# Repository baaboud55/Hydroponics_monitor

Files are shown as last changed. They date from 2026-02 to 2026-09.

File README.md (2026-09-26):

<div align="center">

# 🌿 HydroMisc — Autonomous Hydroponics Monitor

**An open-source, full-stack precision hydroponics controller.**  
Custom PCB · ESP32 Firmware · Python Backend · React Dashboard







</div>

---

## 📖 Overview

**HydroMisc** is a complete, production-ready hydroponics monitoring and autonomous dosing system. It was designed from the ground up to be a consumer appliance — you plug it in, connect to WiFi, select your crop, and the system automatically maintains optimal growing conditions 24/7.

The system is built around a **custom ESP32-based PCB** that reads sensors, drives actuators, and hosts the web interface directly from its flash filesystem — all without needing an internet connection.

### ✨ Key Features

| Feature | Description |
|---|---|
| 🔬 **Multi-Sensor Monitoring** | pH, EC, Dissolved O₂, Water Temp, Air Temp, Humidity, VPD, Water Level, Power Current |
| 🤖 **Autonomous PID Dosing** | Auto-maintains pH and EC using configurable PID controllers with safety limits |
| 🌐 **Zero-Touch Consumer UX** | Select a crop → system sets targets automatically. Accessible from any device on your network |
| 📡 **Real-time WebSocket Dashboard** | Live sensor data streamed to all connected browsers simultaneously |
| 📱 **Cross-Device Sync** | Backend is the single source of truth — phone and PC stay perfectly in sync |
| 💧 **8-Solenoid Irrigation Control** | Full control over 8 solenoid valves via shift register |
| ⚡ **OTA Firmware Updates** | Update firmware wirelessly via Arduino OTA or HTTP update server |
| 🗓️ **Dosing History Log** | All auto-dosing events persisted to SQLite for audit and analysis |

---

## 🏗️ System Architecture

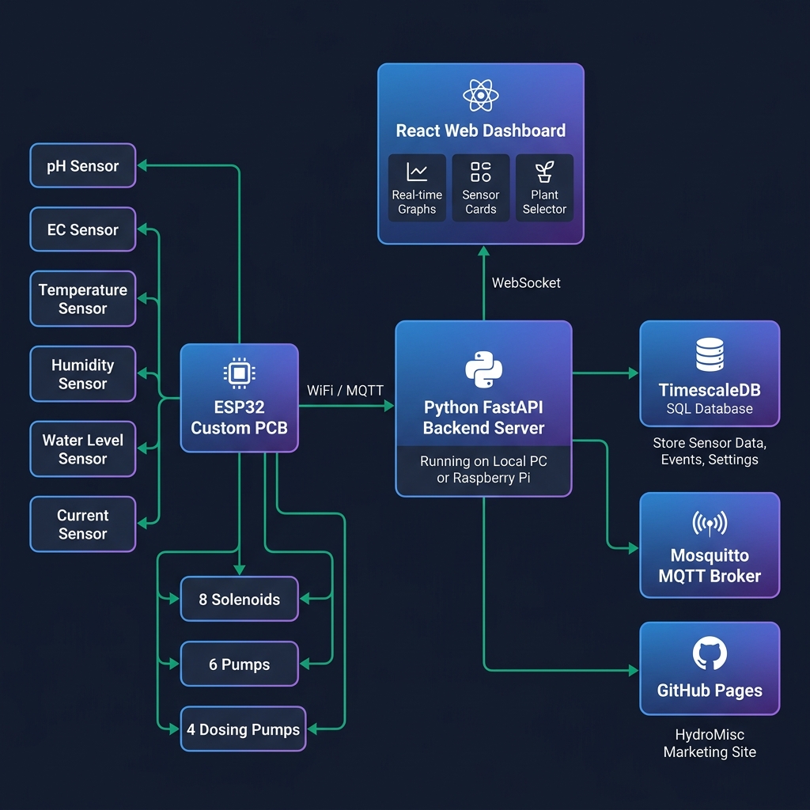
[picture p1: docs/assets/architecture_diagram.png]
System Architecture


### Data Flow

```
ESP32 Custom PCB
  ├── Reads sensors every loop cycle
  ├── Runs autonomous PID control (HydroControl library)
  ├── Serves the React dashboard via LittleFS (port 80)
  └── Publishes sensor data via MQTT
           │
           ▼  WiFi / LAN (MQTT port 1883)
  Python FastAPI Backend
  ├── Subscribes to MQTT sensor topics
  ├── Runs a parallel PID control layer
  ├── Stores config.json and dosing history (SQLite)
  ├── REST API  → http://<host>:8000
  └── WebSocket → ws://<host>:8000/ws
           │
           ▼  WebSocket (real-time push)
  React Web Dashboard
  ├── Consumer View: Plant Selector → System Visualizer
  └── Admin View: Dashboard, Automation, Parameter Config
```

---

## 🗂️ Repository Structure

```
HydroMonitor/
├── firmware/                    # ESP32 PlatformIO project (C++)
│   ├── src/
│   │   └── main.cpp             # Main firmware entry point
│   ├── lib/
│   │   ├── HydroActuators/      # Shift-register solenoid/pump driver
│   │   ├── HydroSensors/        # pH, EC, Temp, Humidity sensor drivers
│   │   ├── HydroDosingPumps/    # Peristaltic dosing pump driver
│   │   ├── HydroControl/        # On-device PID control engine
│   │   └── HydroMQTT/           # MQTT client abstraction
│   ├── data/                    # Web dashboard files (served via LittleFS)
│   └── platformio.ini           # Board config & dependencies
│
├── software/
│   ├── backend/                 # Python FastAPI server
│   │   ├── main.py              # App entry point, API routes, WebSocket
│   │   ├── control_engine.py    # PID controller & safety manager
│   │   ├── config_manager.py    # Persistent configuration (config.json)
│   │   ├── database.py          # SQLite dosing history
│   │   ├── mock_device.py       # MQTT sensor simulator for testing
│   │   └── requirements.txt
│   └── frontend/                # React + Vite dashboard
│       ├── src/
│       │   ├── components/      # UI components (10 total)
│       │   ├── hooks/           # useWebSocket
│       │   ├── services/        # api.js (all REST calls)
│       │   ├── contexts/        # LanguageContext (EN/AR bilingual)
│       │   └── App.jsx          # Router & top-level state
│       └── package.json
│
├── docs/                        # Documentation & GitHub Pages
│   ├── app/                     # GitHub Pages build output
│   └── assets/                  # Diagrams and images
│
└── README.md
```

---

## ⚡ Getting Started

### Prerequisites

| Requirement | Version | Purpose |
|---|---|---|
| Python | 3.10+ | Backend server |
| Node.js | 18+ | Frontend build toolchain |
| PlatformIO | Latest | ESP32 firmware compilation |
| Mosquitto / any MQTT broker | Any | Local MQTT relay (optional) |

---

### 1. Backend Server

```bash
cd software/backend
pip install -r requirements.txt

# Start the server (accessible on your whole local network)
uvicorn main:app --host 0.0.0.0 --port 8000 --reload
```

> On first run, `config.json` is automatically created with safe defaults.

**Key API Endpoints:**

| Method | Endpoint | Description |
|---|---|---|
| `GET` | `/api/state` | Full sensor + automation state snapshot |
| `WS` | `/ws` | Real-time WebSocket stream (1 Hz) |
| `GET` | `/api/config` | Read full configuration |
| `POST` | `/api/config/parameter` | Update pH/EC target or tolerance |
| `POST` | `/api/config/crop/{id}` | Set active crop (syncs to all browsers) |
| `POST` | `/api/config/automation/{param}/{enabled}` | Enable/disable PID automation |
| `GET` | `/api/dosing/history` | Retrieve dosing log |
| `POST` | `/api/dosing/manual` | Trigger a manual pump dose |
| `POST` | `/api/dosing/reset` | Reset PID controller state |
| `POST` | `/api/calibrate` | Send calibration command to ESP32 |
| `POST` | `/api/actuators/solenoid/{index}/{state}` | Control solenoid valve 0–7 |
| `POST` | `/api/actuators/pump/{index}/{state}` | Control circulation pump 0–5 |
| `POST` | `/api/actuators/main_pump/{state}` | Control main circulation pump |

**For testing without hardware**, set `MQTT_ENABLED = False` in `main.py` — the backend will simulate sensor data internally. Alternatively, run the MQTT mock device in a separate terminal:
```bash
python mock_device.py
```

---

### 2. Frontend Dashboard

```bash
cd software/frontend
npm install
npm run dev
```

Dashboard available at **`http://localhost:5173`**.

The app auto-detects the environment:
- **On localhost / local IP** → Boots directly into the Consumer Dashboard (no setup needed)
- **On GitHub Pages** → Boots into the Marketing Demo

To build the production bundle (outputs to `docs/app/` for GitHub Pages and `firmware/data/` for the ESP32 filesystem):
```bash
npm run build
```

---

### 3. Firmware (ESP32)

#### First-time Setup

1. Install [PlatformIO](https://platformio.org/) (VS Code extension recommended).
2. Open the `firmware/` folder in VS Code.
3. Build and upload firmware:
   ```bash
   pio run --target upload
   ```
4. Upload the web dashboard filesystem:
   ```bash
   pio run --target uploadfs
   ```

#### WiFi Configuration

On first boot, the ESP32 creates a WiFi access point:
- **SSID:** `HydroMisc-Setup`
- **Password:** `password`

Connect to it and you'll be automatically redirected to the WiFi configuration portal. Enter your network credentials and the device will restart and connect.

#### OTA (Over-The-Air) Updates

After first setup, you **never need a USB cable again**.

**Via Arduino OTA (PlatformIO):**
```bash
# platformio.ini already has: upload_protocol = espota
pio run --target upload
```

**Via HTTP Update Server:**  
Navigate to `http://hydromonitor.local/update` in your browser and upload a `.bin` file.

#### mDNS / Local DNS

The device registers itself on your network as `hydromonitor.local`. Access the dashboard at:
```
http://hydromonitor.local
```

---

## 📌 GPIO Pinout

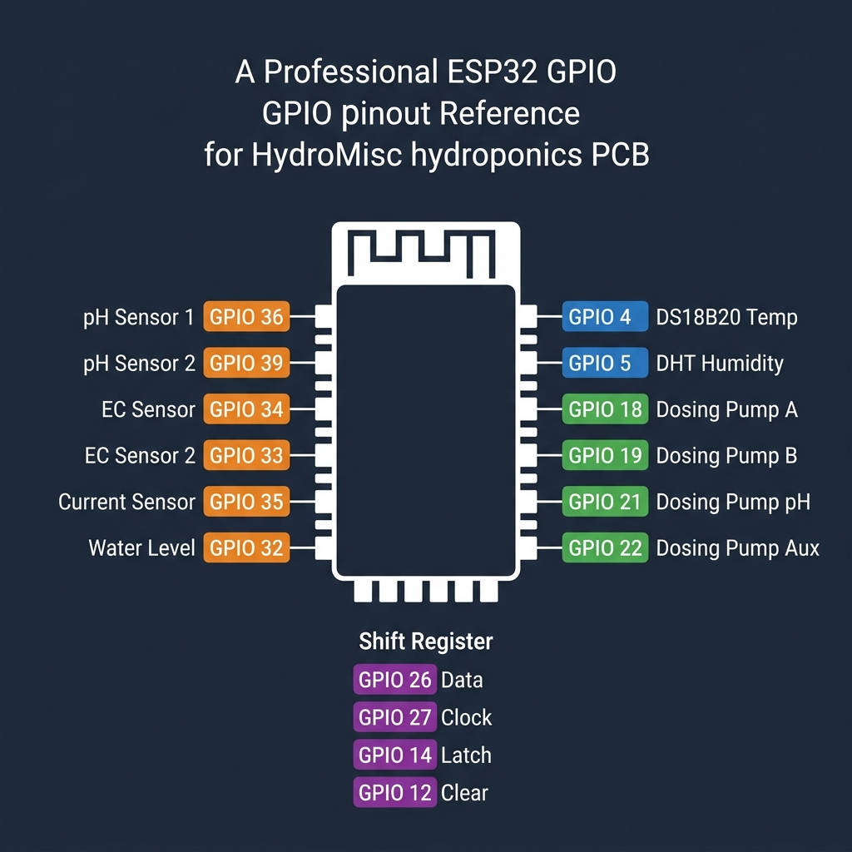
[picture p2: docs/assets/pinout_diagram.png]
Pinout Diagram


### Analog Inputs (Sensors)

| GPIO | ADC Channel | Function |
|---|---|---|
| `36` | ADC1_CH0 | pH Probe (Primary) |
| `39` | ADC1_CH3 | pH Probe (Secondary / Reference) |
| `34` | ADC1_CH6 | EC Probe (EC_0) |
| `33` | ADC1_CH5 | EC Probe (EC_1) |
| `35` | ADC1_CH7 | Current Sensor |
| `32` | ADC1_CH4 | Water Level Sensor / DC Resistance |

### Digital Inputs (Sensors)

| GPIO | Function |
|---|---|
| `4`  | DS18B20 Water Temperature (1-Wire) |
| `5`  | DHT / AM2301 Air Temp & Humidity |

### Actuators — Direct PWM (Dosing Pumps)

| GPIO | Function |
|---|---|
| `18` | Dosing Pump A (Nutrient A) |
| `19` | Dosing Pump B (Nutrient B) |
| `21` | Dosing Pump pH (pH Up/Down) |
| `22` | Dosing Pump Aux (Spare) |

### Actuators — Shift Register (74HC595, 16-bit chain)

| GPIO | Shift Register Pin | Function |
|---|---|---|
| `26` | SI (Data) | Shift Register Data |
| `27` | SCK (Clock) | Shift Register Clock |
| `14` | RCK (Latch) | Shift Register Latch |
| `12` | nRCLR (Clear) | Shift Register Clear (Active Low) |

**Shift Register Bit Map (16 bits):**

| Bits | Assignment |
|---|---|
| 0–7  | Solenoid Valves 0–7 |
| 8–13 | Circulation Pumps 0–5 |
| 14 | Main Pump |
| 15 | Debug Status LED |

### EC Measurement Gates

| GPIO | Function |
|---|---|
| `25` | EC Measurement Gate (+) |
| `15` | EC Measurement Gate (−) |

---

## 🔌 Hardware Wiring Guide (Hydromisc PCBA)

The Hydromisc custom PCBA provides dedicated plug-and-play ports for all hydroponic peripherals.

### PCB Layout Overview
Hydromisc PCBA Top View

### Power Side (Actuators & Pumps)
Power Side Pinout

This side handles all high-current 12V outputs. Note the varying current limits for each block:

```mermaid
flowchart LR
    subgraph Hydromisc Power Ports
        S[Solenoid Ports<br>8x 12V 1.0A]
        P[Pump Ports<br>6x 12V 0.5A]
        D[Dosing Ports<br>4x 12V 0.25A]
    end
    
    WaterValve[12V Solenoid Valve] -.-> S
    MainPump[Small Circulation Pump<br>>250mA] -.-> P
    AirPump[12V Air Pump] -.-> P
    DoseA[Nutrient A Doser<br><250mA] -.-> D
    DoseB[Nutrient B Doser<br><250mA] -.-> D
    DosePH[pH Down Doser<br><250mA] -.-> D
```

### 🔌 Exact Software-to-Hardware Mapping

When you click a button in the HydroMisc Web Dashboard, the software activates a specific port on the board. Follow this diagram to wire your hardware correctly so it works instantly!

```mermaid
flowchart LR
    %% Software Interface Layer
    subgraph Dashboard[🖥️ HydroMisc Web Dashboard]
        BtnMain[Main Pump Toggle]
        BtnCirc[Circulation Pumps 1-5]
        BtnSol[Solenoid Valves 0-7]
        BtnDoseA[Nutrient A Auto-Dose]
        BtnDoseB[Nutrient B Auto-Dose]
        BtnDosePH[pH Down Auto-Dose]
        BtnDoseAux[Aux Auto-Dose]
    end

    %% Hardware Board Layer
    subgraph PCBA[🔌 Hydromisc PCBA Physical Ports]
        PortP0[Pump Port #0<br/>labeled 'big_pump']
        PortP15[Pump Ports #1-5]
        PortS07[Solenoid Ports #0-7]
        PortDA[Dosing Port A]
        PortDB[Dosing Port B]
        PortDPH[Dosing Port pH]
        PortDAux[Dosing Port AUX]
    end

    %% Actuator Layer
    subgraph Actuators[⚙️ Plug Your Hardware Here]
        MainPump[Main Water Cycle Pump<br/>0.5A max]
        CircPump[Air / Circ Pumps<br/>0.5A max]
        Solenoid[Water Valves / Relays<br/>1.0A max]
        PeriA[Peristaltic Pump A<br/>0.25A max]
        PeriB[Peristaltic Pump B<br/>0.25A max]
        PeriPH[Peristaltic Pump pH<br/>0.25A max]
        PeriAux[Peristaltic Pump Aux<br/>0.25A max]
    end

    %% Connections
    BtnMain == Triggers ==> PortP0
    PortP0 -.-> MainPump
    
    BtnCirc == Triggers ==> PortP15
    PortP15 -.-> CircPump
    
    BtnSol == Triggers ==> PortS07
    PortS07 -.-> Solenoid
    
    BtnDoseA == Triggers ==> PortDA
    PortDA -.-> PeriA
    
    BtnDoseB == Triggers ==> PortDB
    PortDB -.-> PeriB
    
    BtnDosePH == Triggers ==> PortDPH
    PortDPH -.-> PeriPH
    
    BtnDoseAux == Triggers ==> PortDAux
    PortDAux -.-> PeriAux

    %% Styling
    classDef soft fill:#1e293b,stroke:#3b82f6,stroke-width:2px,color:#fff;
    classDef hard fill:#14532d,stroke:#22c55e,stroke-width:2px,color:#fff;
    classDef act fill:#450a0a,stroke:#ef4444,stroke-width:2px,color:#fff;
    
    class BtnMain,BtnCirc,BtnSol,BtnDoseA,BtnDoseB,BtnDosePH,BtnDoseAux soft;
    class PortP0,PortP15,PortS07,PortDA,PortDB,PortDPH,PortDAux hard;
    class MainPump,CircPump,Solenoid,PeriA,PeriB,PeriPH,PeriAux act;
```

> 🚨 **CRITICAL WIRING RULE:** Notice in the board images that every single port block has its own dedicated `+12V` and `GND` screw terminal. **DO NOT twist your motor grounds together!** You must strip the two wires for each pump and screw them directly into their own dedicated block. Bridging grounds together forces all power through a single trace and will permanently burn out the PCB!
Sensor Side Pinout

```mermaid
flowchart LR
    subgraph Hydromisc Sensor Ports
        BNC_PH[pH BNC Port]
        BNC_EC[EC BNC Port]
        DIG_0[Digital Expansion 0]
        DIG_1[Digital Expansion 1]
    end
    
    PH_Probe[Commercial pH Probe] -.-> BNC_PH
    EC_Probe[Commercial EC Probe] -.-> BNC_EC
    WaterTemp[DS18B20 Water Temp] -.-> DIG_0
    AirTemp[DHT22 Air Temp/Humidity] -.-> DIG_1
```

---

## ⚙️ Configuration Reference

All parameters are configurable via the dashboard **Config tab** or by editing `software/backend/config.json` directly.

```json
{
  "active_crop": "lettuce",
  "ph": {
    "target": 6.0,
    "tolerance": 0.2,
    "enabled": true,
    "min_value": 4.0,
    "max_value": 8.0
  },
  "ec": {
    "target": 1.5,
    "tolerance": 0.1,
    "enabled": false,
    "min_value": 0.5,
    "max_value": 3.0
  },
  "pid_tuning": {
    "ph": { "kp": 0.5, "ki": 0.1, "kd": 0.05 },
    "ec": { "kp": 0.3, "ki": 0.05, "kd": 0.02 }
  },
  "safety": {
    "max_ph_dose_ml": 50.0,
    "max_ec_dose_ml": 100.0,
    "min_dose_interval_sec": 300,
    "sensor_timeout_sec": 30
  },
  "mqtt": {
    "broker": "192.168.1.100",
    "port": 1883,
    "device_id": "hydro-misc-01"
  }
}
```

### Supported Crop Profiles

When a crop is selected in the dashboard, pH and EC targets are automatically pushed to the backend PID controllers.

| Crop | Target pH | Target EC (mS/cm) | Target Temp |
|---|---|---|---|
| 🥬 Lettuce | 6.0 | 1.0 | 20 °C |
| 🍅 Tomatoes | 6.0 | 2.7 | 23.5 °C |
| 🌿 Basil | 6.0 | 1.3 | 24 °C |
| 🍓 Strawberries | 5.8 | 1.2 | 20.5 °C |

---

## 🚦 LED Status Codes

The debug LED on the PCB communicates system status without needing Serial Monitor access.

| Pattern | Mode | Meaning |
|---|---|---|
| Rapid blink (100ms) | `BOOTING` | System initializing |
| Slow pulse (800ms on/off) | `WIFI_SETUP` | WiFi AP portal is active — connect to configure |
| Fast strobe (50ms) | `OTA_UPDATE` | Firmware upload in progress |
| Heartbeat (double-tap + 1.7s off) | `NORMAL` | Healthy operation |
| Triple flash SOS | `ERROR` | Critical fault — check Serial Monitor |

---

## 📦 Enclosure

The system is designed to be housed in a **panel-mount waterproof enclosure** suitable for a grow room or utility area.

### Recommended Enclosure Specs

- **Type:** IP65-rated ABS plastic enclosure
- **Size:** ~200×120×75mm (adjust for your PCB dimensions)
- **Mounting:** DIN rail clip or M4 wall screws
- Cable gland fittings for all probe cables and pump tubing
- PCB mounted on brass standoffs inside the enclosure
- Position the ESP32 antenna toward the enclosure wall or use an external antenna for best WiFi signal

### External Connections

| Connector Type | Signals |
|---|---|
| BNC or SMA | pH probe(s), EC probe(s) |
| RJ11 / JST-XH | DS18B20 water temperature probe |
| JST-XH 3-pin | DHT / AM2301 air temp & humidity sensor |
| Screw terminal strip | 12V solenoid valve outputs (×8) |
| Screw terminal strip | Dosing pump power lines (×4) |
| Screw terminal strip | Circulation pump relay outputs (×6) |
| Barrel Jack (5.5/2.1mm) | 12V DC power input |
| Micro-USB / USB-C | Programming & Serial monitor |

---

## 🌐 Network & Ports Summary

| Service | Protocol | Port | Notes |
|---|---|---|---|
| ESP32 Web Server | HTTP | **`80`** | Dashboard (LittleFS) + `/api/state` + `/api/config` + `/update` |
| Python Backend API | HTTP | **`8000`** | Full REST API for the dashboard |
| Python WebSocket | WS | **`8000/ws`** | Real-time 1 Hz sensor stream to browser |
| MQTT Broker | TCP | **`1883`** | Sensor data & actuator commands |
| mDNS Discovery | UDP | `5353` | `hydromonitor.local` hostname resolution |
| Serial Monitor | UART | `115200 baud` | Firmware debugging via USB |

---

## 🔄 MQTT Topics

The ESP32 and Python backend communicate over MQTT with the following topic structure:

**Sensor Data (Published by ESP32):**
```
hydro/status/<device_id>/ph
hydro/status/<device_id>/ec
hydro/status/<device_id>/water_temp
hydro/status/<device_id>/air_temp
hydro/status/<device_id>/humidity
hydro/status/<device_id>/water_level
hydro/status/<device_id>/power_current
```

**Actuator Commands (Published by Python Backend → Received by ESP32):**
```
hydro/<device_id>/control/dosing/<pump_index>/dose    → duration in ms
hydro/<device_id>/control/solenoid/<index>            → "1" or "0"
hydro/<device_id>/control/pump/<index>                → "1" or "0"
hydro/<device_id>/control/main_pump                   → "1" or "0"
hydro/<device_id>/control/calibrate/<sensor>          → calibration string
```

> Default `device_id`: `hydro-misc-01` (configurable in `config.json`)

---

## 🖥️ Dashboard

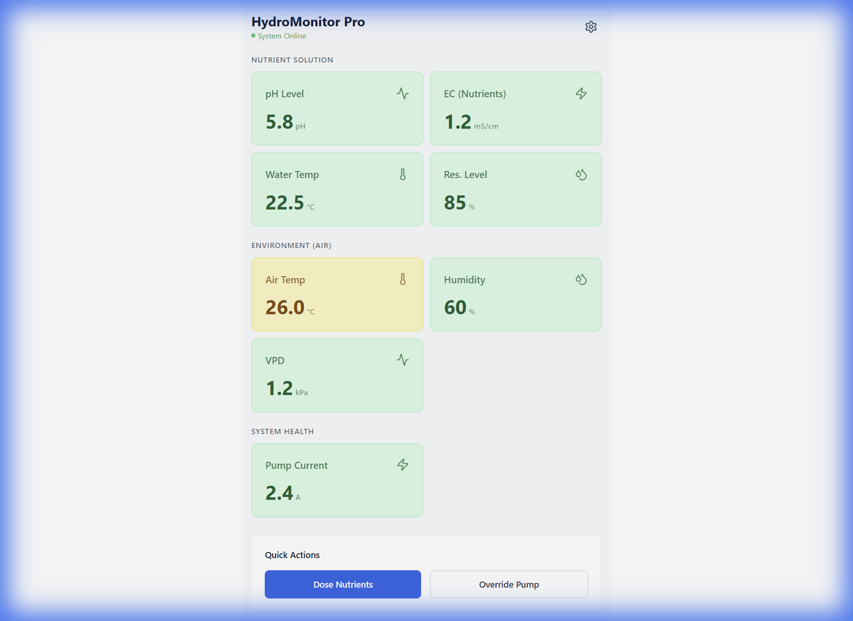
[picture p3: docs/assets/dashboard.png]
Dashboard Screenshot


> **Live Demo:** [https://baaboud55.github.io/Hydroponics_monitor/app/](https://baaboud55.github.io/Hydroponics_monitor/app/)  
> *(Demo mode uses simulated data — no hardware required to explore the full UI.)*

---

## 🏢 About

**HydroMisc** is developed and maintained by **Baaboud Electronics** — an engineering company specialising in embedded systems, IoT solutions, and precision agriculture technology.

> 🌍 **Company & Product Website:** [https://baaboud55.github.io/Hydroponics_monitor/](https://baaboud55.github.io/Hydroponics_monitor/)

We build custom embedded hardware and software solutions for automation, monitoring, and control systems across agricultural and industrial sectors.

---

## 🛣️ Roadmap

- [ ] Automated grow scheduling (day/night lighting cycles)
- [x] Historical charting with time-range selection
- [ ] Push notifications (email / Telegram) on out-of-range sensor alerts
- [ ] Multi-zone support (multiple ESP32 devices on one backend)
- [ ] Mobile app (React Native)
- [ ] Cloud dashboard option (opt-in, privacy-first)

---

## 🤝 Contributing

Contributions are welcome! Please open an issue first to discuss what you'd like to change.

1. Fork the repository
2. Create a feature branch (`git checkout -b feature/amazing-feature`)
3. Commit your changes (`git commit -m 'feat: add amazing feature'`)
4. Push to the branch (`git push origin feature/amazing-feature`)
5. Open a Pull Request

---

## 📄 License

This project is licensed under the **MIT License** — see the [LICENSE](LICENSE) file for details.

---

<div align="center">
Made with 💚 for growers everywhere.<br>
<a href="https://baaboud55.github.io/Hydroponics_monitor/">baaboud55.github.io/Hydroponics_monitor</a>
</div>

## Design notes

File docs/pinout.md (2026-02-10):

# Hydromisc Pinout Reference

## Analog Inputs (Sensors)
- **pH Probe 1**: GPIO 36 (ADC1_CH0)
- **pH Probe 2**: GPIO 39 (ADC1_CH3)
- **EC Probe 1**: GPIO 34 (ADC1_CH6)
- **EC Probe 2**: GPIO 33 (ADC1_CH5)
- **Current Sense**: GPIO 35 (ADC1_CH7)
- **DC Resistance**: GPIO 32 (ADC1_CH4)

## Digital I/O
- **DS18B20 / AM2301 Temp**: 
    - Port 0: In GPIO 2, Out GPIO 4
    - Port 1: In GPIO 17, Out GPIO 23

## Actuators (Shift Register - 74HC595 likely)
**Control Pins:**
- **Data (SI)**: GPIO 26
- **Clock (SCK)**: GPIO 27
- **Latch (RCK)**: GPIO 14
- **Clear (nRCLR)**: GPIO 12

**Shift Register Map (16 bits):**
- **Bits 0-7**: Solenoids 0-7
- **Bits 8-13**: Pumps 0-5
- **Bit 14**: Big Pump
- **Bit 15**: Debug LED

## Actuators (Direct PWM/LEDC)
- **Dosing Pump A**: GPIO 18
- **Dosing Pump B**: GPIO 19
- **Dosing Pump pH**: GPIO 21
- **Dosing Pump Aux**: GPIO 22

## Other
- **EC Gates**: GPIO 25, 15

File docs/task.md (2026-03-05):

# Hydroponic Automation Project

- [/] Requirements Gathering
    - [x] Define hardware scope: **Hydromisc (ESP32 based)**
    - [x] Identify key sensors: pH, EC, Water Level (supported by Hydromisc)
    - [x] Identify actuators: Solenoids, Pumps, Peristaltic Dosing (supported by Hydromisc)
    - [ ] Determine software stack (Web Dashboard, Mobile App, Local/Cloud)
- [ ] System Design
    - [x] **Research Hydromisc Pinout** (Completed)
    - [ ] Design Mobile-First UI (PWA)
    - [ ] Define API for Mobile App <-> Backend
- [ ] Implementation - Firmware (ESP32/PlatformIO)
    - [ ] Initialize PlatformIO Project
    - [ ] Implement **WiFiManager** (User friendly WiFi setup)
    - [ ] Implement Shift Register Driver (74HC595)
    - [ ] Implement MQTT Client & Auto-Discovery
    - [ ] Implement Sensor/Actuator Logic
- [ ] Implementation - Backend (Python)
    - [x] Setup FastAPI + MQTT
    - [x] Implement "Smart Rules" (Consumer friendly presets)
- [ ] Implementation - Mobile App (PWA/React)
    - [x] Initialize React Vite (configured as PWA)
    - [x] **Create Dashboard Components** (Expanded to support all sensors)
    - [x] Create Control Panel (Pump/Light toggles)
    - [ ] Create Calibration Wizard (pH/EC)
    - [x] Implement API/Socket connection to Backend
- [ ] Verification
    - [ ] Test Scenarios (Low water, High Temp, etc.)
    - [ ] End-to-end simulation

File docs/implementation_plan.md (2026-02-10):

# Hydroponic Automation System - Implementation Plan

## Goal Description
Build a system to automate and monitor a hydroponic growing setup. The system should read sensor data (pH, EC, water level, etc.) and control actuators (pumps, lights) based on defined rules or manual input.

## User Review Required
> [!IMPORTANT]
> **Architecture Confirmation**
> We are proceeding with **New Firmware** (PlatformIO/Arduino) and **MQTT** for connectivity.
>
> **Next Steps:**
> 1.  **Pinout Research**: I need to find the specific GPIO pin mapping for the Hydromisc PCB (Solenoids, Pumps, Sensors) to write the firmware.
> 2.  **Environment Setup**: I will create a `firmware` folder (PlatformIO) and a `software` folder (Backend/Frontend).
>
> **Request**: If you have the Hydromisc schematics or pinout documentation handy, please share it. Otherwise, I will search for it in the open-source repo.

## Proposed Architecture
### 1. Hardware / Firmware (ESP32)
-   **Framework**: PlatformIO (Arduino Core) for easy library management.
-   **Communication**: connect to WiFi -> Connect to MQTT Broker.
-   **Logic**:
    -   Publish Sensor Data (e.g., `hydro/status/ph`, `hydro/status/ec`) every X seconds.
    -   Subscribe to Control Topics (e.g., `hydro/control/pump_a`) to toggle relays.
    -   Safety: Hard-coded safety limits (e.g., auto-off pump if run too long).

### 2. Backend / Broker (The "Brain")
-   **Broker**: Mosquitto (standard MQTT broker).
-   **Controller**: Python (FastAPI) service.
    -   Listens to sensor topics.
    -   Logs data to SQLite/TimescaleDB.
    -   Runs automation rules (e.g., "If pH < 5.5, dose pH Up").

### 3. Frontend (The "Face")
-   **Tech**: React (Vite) + TailwindCSS.
-   **Features**:
    -   Real-time Dashboard (Gauges/Charts).
    -   Manual Override Switches.
    -   Settings (Thresholds, WiFi Config).

## Verification Plan
### Automated Tests
- Unit tests for control logic (e.g., "Does pump turn off when water full?").
### Manual Verification
- Simulate sensor readings and verify dashboard updates.
- Verify manual override controls.

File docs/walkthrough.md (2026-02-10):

# Frontend Verification - Hydroponic Monitor PWA

## Overview
We have successfully initialized the **Frontend** using React, Vite, and TailwindCSS. The project is configured as a Progressive Web App (PWA), meaning it can be installed on mobile devices.

## Dashboard Preview
The dashboard is running locally at `http://localhost:5173`.
Here is a capture of the current **HydroMonitor Pro** UI state:

HydroMonitor Pro Dashboard

## Features Implement (UI Only)
- **Status Header**: Shows system online status.
- **Nutrient Sensors**: pH, EC, Water Temp, Reservoir Level.
- **Environment Sensors**: Air Temp, Humidity, VPD (Calculated).
- **System Health**: Pump Current Monitoring.
- **Quick Actions**: Buttons for manual dosing and pump override.

## Next Steps
- Connect this UI to the Python Backend via WebSockets.
- Replace mock data with real MQTT data from the Firmware.

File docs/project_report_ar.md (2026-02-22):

# تقرير المشروع: نظام مراقبة وأتمتة الزراعة المائية

## مقدمة: ما هي الزراعة المائية؟

**الزراعة المائية** هي طريقة زراعة النباتات بدون تربة، حيث تنمو النباتات في محلول مائي غني بالعناصر الغذائية. تعتمد هذه التقنية على توفير جميع العناصر اللازمة للنمو (النيتروجين، الفسفور، البوتاسيوم، وغيرها) مباشرة في الماء.

### لماذا الزراعة المائية؟

- ✅ **توفير الماء**: تستخدم ماء أقل بنسبة 90% من الزراعة التقليدية
- ✅ **نمو أسرع**: تنمو النباتات بشكل أسرع بنسبة 30-50%
- ✅ **إنتاجية أعلى**: يمكن زراعة كمية أكبر في مساحة أقل
- ✅ **تحكم دقيق**: يمكن التحكم بالبيئة بدقة (درجة الحموضة، التغذية، الحرارة)
- ✅ **لا تحتاج تربة**: مناسبة للمناطق الصحراوية أو الحضرية

### التحديات

لكن الزراعة المائية تحتاج **مراقبة دقيقة ومستمرة** لعدة عوامل:
- **درجة الحموضة**: يجب أن تكون بين 5.5 - 6.5 لامتصاص أمثل للعناصر
- **التوصيل الكهربائي**: يقيس تركيز العناصر الغذائية المذابة في الماء
- **درجة حرارة الماء**: المثالية بين 18 - 22 درجة مئوية
- **مستوى الماء**: للتأكد من عدم نفاد المحلول الغذائي

**هنا يأتي دور مشروعنا!** 🚀

---

## هدف المشروع

بناء **نظام مراقبة وأتمتة ذكي** للزراعة المائية يقوم بـ:

1. **المراقبة التلقائية** لجميع المعايير المهمة (الحموضة، التوصيل الكهربائي، درجة الحرارة، الرطوبة، وغيرها)
2. **التحكم الآلي** في المضخات والصمامات لضبط المحلول الغذائي تلقائياً
3. **الإنذارات الفورية** عند حدوث أي مشكلة (مستوى ماء منخفض، حموضة غير مناسبة، وغيرها)
4. **واجهة مستخدم سهلة** على الهاتف المحمول لمراقبة النظام من أي مكان (يمكن تثبيتها كتطبيق)
5. **قواعد ذكية جاهزة** مبرمجة مسبقاً للمبتدئين (مثل: إذا انخفضت الحموضة، أضف محلول رفع الحموضة تلقائياً)

---

## العتاد المستخدم

نستخدم لوحة **هايدروميسك** المبنية على معالج **إي إس بي 32**، وهي مصممة خصيصاً للزراعة المائية:

### المستشعرات
- 📊 **مستشعر الحموضة** (عدد 2): لقياس درجة حموضة الماء بدقة
- 📊 **مستشعر التوصيل الكهربائي** (عدد 2): لقياس تركيز الأملاح المعدنية والعناصر الغذائية
- 🌡️ **مستشعر حرارة رقمي** (دي إس 18 بي 20): لقياس درجة حرارة الماء
- 🌡️ **مستشعر الحرارة والرطوبة** (إيه إم 2301): لقياس درجة حرارة ورطوبة الهواء المحيط
- 📏 **مستشعر مستوى الماء**: للتحقق من كمية الماء في الخزان
- ⚡ **مستشعر التيار الكهربائي**: لمراقبة استهلاك المضخات واكتشاف الأعطال

### المحركات والمتحكمات
- 💧 **8 صمامات كهربائية**: للتحكم في فتح وإغلاق تدفق المحاليل المختلفة
- 🔄 **6 مضخات عادية**: للري وتدوير المحلول الغذائي
- 💉 **4 مضخات دقيقة**: لإضافة المحاليل المركزة بكميات صغيرة ومحددة (محلول رفع الحموضة، محلول خفض الحموضة، محلول أ، محلول ب)
- 💡 **مضخة كبيرة**: للعمليات الرئيسية مثل ملء الخزان

### آلية التحكم
- استخدام **سجل الإزاحة** (شريحة 74HC595) للتحكم بـ 16 مُخرج باستخدام 4 أطراف فقط من المعالج
- التحكم بسرعة المضخات الدقيقة عن طريق **تعديل عرض النبضة** (تقنية بي دبليو إم)

> [!NOTE]
> لدينا [ملف توثيق كامل](file:///d:/Github/HydroMonitor/docs/pinout.md) يحتوي على جميع توصيلات GPIO للعتاد

---

## معمارية النظام

المشروع مقسم إلى **ثلاثة أجزاء رئيسية** تعمل معاً بشكل متكامل:

```mermaid
flowchart TB
    subgraph Hardware["🔧 العتاد - Hydromisc (ESP32)"]
        sensors[المستشعرات<br/>pH, EC, Temp, etc.]
        actuators[المضخات والصمامات]
        firmware[البرمجية المدمجة<br/>Firmware]
    end
    
    subgraph Backend["🧠 الخادم - Backend"]
        mqtt[MQTT Broker<br/>Mosquitto]
        api[Python FastAPI<br/>+ Smart Rules]
        db[(قاعدة البيانات<br/>SQLite)]
    end
    
    subgraph Frontend["📱 الواجهة - PWA"]
        dashboard[لوحة التحكم<br/>Dashboard]
        controls[أزرار التحكم<br/>Manual Override]
    end
    
    sensors --> firmware
    firmware --> actuators
    firmware <-->|MQTT| mqtt
    mqtt <--> api
    api --> db
    dashboard <-->|WebSocket| api
    controls <-->|REST API| api
    
    style Hardware fill:#e1f5ff
    style Backend fill:#fff3e0
    style Frontend fill:#f3e5f5
```

### 1️⃣ البرمجية المدمجة (الكود المثبت على المعالج)
- **لغة البرمجة**: سي بلس بلس باستخدام منصة بلاتفورم آي أو
- **الوظائف الرئيسية**:
  - قراءة جميع المستشعرات كل عدة ثوانٍ
  - إرسال القراءات عبر بروتوكول الاتصال إم كيو تي تي
  - استقبال الأوامر للتحكم بالمضخات والصمامات
  - الحماية التلقائية (مثل إيقاف المضخة تلقائياً إذا عملت لفترة طويلة جداً)

### 2️⃣ الخادم (العقل المدبر للنظام)
- **لغة البرمجة**: بايثون باستخدام إطار فاست إيه بي آي
- **الوظائف الرئيسية**:
  - استقبال بيانات المستشعرات وحفظها في قاعدة البيانات
  - تطبيق **القواعد الذكية الآلية** (مثال: إذا كانت الحموضة منخفضة → تشغيل مضخة رفع الحموضة تلقائياً)
  - توفير اتصال سريع للواجهة للحصول على بيانات لحظية مباشرة
  - توفير واجهة برمجية للتحكم اليدوي من الهاتف

### 3️⃣ واجهة المستخدم (التطبيق على الهاتف)
- **التقنيات**: تطبيق ويب تقدمي يعمل كتطبيق حقيقي
- **الوظائف الرئيسية**:
  - عرض جميع القراءات في لوحة تحكم جميلة وسهلة الاستخدام
  - أزرار للتحكم اليدوي بالمضخات والصمامات
  - معالج ذكي لمعايرة المستشعرات خطوة بخطوة
  - يمكن تثبيتها كتطبيق على الهاتف المحمول وتعمل حتى بدون إنترنت

---

## ما تم إنجازه حتى الآن ✅

### مرحلة التخطيط والبحث
- ✅ تحديد العتاد: اخترنا لوحة هايدروميسك كمنصة رئيسية
- ✅ دراسة جميع المستشعرات والمحركات المتوفرة في اللوحة
- ✅ **توثيق كامل لتوصيلات الأطراف الإلكترونية** ([ملف التوصيلات](file:///d:/Github/HydroMonitor/docs/pinout.md))
- ✅ تصميم المعمارية الكاملة للنظام بجميع أجزائه

### البرمجية المدمجة على المعالج
- ✅ إنشاء مشروع برمجي على منصة بلاتفورم آي أو
- ✅ إعداد ملف التكوين ([ملف الإعدادات](file:///d:/Github/HydroMonitor/firmware/platformio.ini))
- 🔄 **جارٍ العمل**: تطبيق التحكم بالمضخات الدقيقة عبر تعديل عرض النبضة
- 🔄 **جارٍ العمل**: تطبيق نظام الاتصال بالشبكة اللاسلكية بسهولة للمستخدم
- 🔄 **جارٍ العمل**: برمجة سجل الإزاحة للتحكم بالصمامات والمضخات
- 📝 **قادم**: تطبيق بروتوكول الاتصال وإرسال بيانات المستشعرات

### الخادم (البرنامج الوسيط)
- ✅ إعداد الخادم بلغة بايثون مع إطار العمل السريع
- ✅ تطبيق الاتصال اللحظي السريع للبيانات المباشرة
- ✅ تطبيق **القواعد الذكية الجاهزة** للمبتدئين
- ✅ الكود جاهز وقابل للتشغيل ([ملف الكود الرئيسي](file:///d:/Github/HydroMonitor/software/backend/main.py))

### واجهة المستخدم (التطبيق)
- ✅ إنشاء مشروع تطبيق الويب التقدمي
- ✅ إعداد نظام التصميم الجميل
- ✅ إعداده كتطبيق قابل للتثبيت على الهاتف
- ✅ **تصميم لوحة التحكم الكاملة** مع جميع المستشعرات:
  - مستشعرات المحلول الغذائي (الحموضة، التوصيل الكهربائي، حرارة الماء، مستوى الماء)
  - مستشعرات البيئة المحيطة (حرارة الهواء، الرطوبة، ضغط البخار)
  - مراقبة صحة النظام (استهلاك المضخات الكهربائي)
- ✅ أزرار التحكم السريع لتشغيل المضخات يدوياً
- 📝 **قادم**: ربط الواجهة بالخادم للحصول على بيانات حقيقية
- 📝 **قادم**: معالج المعايرة الذكي خطوة بخطوة

> [!TIP]
> يمكنك الاطلاع على مخطط المهام الكامل في [task.md](file:///d:/Github/HydroMonitor/docs/task.md)

---

## ما المطلوب إنجازه (الخطوات القادمة) 📋

### أولوية عالية 🔥
1. **إكمال البرمجية المدمجة على المعالج**:
   - حل مشكلة التجميع الحالية للمضخات الدقيقة
   - تطبيق نظام الاتصال السهل بالشبكة اللاسلكية
   - برمجة شريحة سجل الإزاحة
   - تطبيل بروتوكول الاتصال بالخادم

2. **اختبار التكامل بين الأجزاء**:
   - التأكد من إرسال البيانات من المعالج إلى الخادم بنجاح
   - ربط تطبيق الهاتف بالخادم

### أولوية متوسطة 🟡
3. **إضافة ميزات التحكم**:
   - لوحة التحكم بالمضخات والصمامات من التطبيق
   - معالج ذكي لمعايرة المستشعرات خطوة بخطوة

4. **القواعد الذكية والأتمتة**:
   - تطبيق السيناريوهات التلقائية (إضافة المحاليل تلقائياً)
   - إنذارات فورية عند وجود مشاكل عبر إشعارات الهاتف

### أولوية منخفضة 🟢
5. **التحسينات والإضافات**:
   - حفظ البيانات التاريخية ورسمها بيانياً
   - إضافة ميزات متقدمة حسب الحاجة

---

## الفائدة المتوقعة من المشروع 🎯

هذا النظام سيوفر:
- ⏱️ **توفير الوقت**: لا حاجة لقياس الحموضة والتوصيل الكهربائي يدوياً كل يوم
- 🎯 **دقة أعلى**: النظام يراقب على مدار الساعة ويتدخل فوراً عند الحاجة
- 📊 **بيانات تاريخية شاملة**: لتحليل أداء النباتات وتحسين الإنتاجية باستمرار
- 🔔 **راحة البال**: إشعارات فورية على الهاتف عند وجود مشاكل حتى لو كنت خارج المنزل
- 🚀 **قابلية التوسع**: يمكن إضافة المزيد من الأحواض أو الميزات لاحقاً بسهولة

---

## التقنيات والأدوات المستخدمة 🛠️

| المجال | التقنية | الغرض |
|---|---|---|
| **العتاد** | معالج إي إس بي 32 (لوحة هايدروميسك) | معالج قوي مع شبكة لاسلكية مدمجة |
| **البرمجية المدمجة** | منصة بلاتفورم آي أو + إطار أردوينو | بيئة برمجة احترافية للمعالجات |
| **بروتوكول الاتصال** | إم كيو تي تي (موسكيتو) | بروتوكول خفيف وسريع لتبادل البيانات |
| **الخادم** | بايثون + إطار فاست إيه بي آي | خادم سريع وعصري للواجهات البرمجية |
| **قاعدة البيانات** | إس كيو إل لايت | تخزين البيانات محلياً بدون تعقيد |
| **واجهة المستخدم** | ريآكت + فايت + تيلويند | إطار عمل سريع لواجهات جميلة |
| **نوع التطبيق** | تطبيق ويب تقدمي | يعمل على الهاتف كتطبيق حقيقي |

---

## كيف يمكنك المساعدة؟ 🤝

يمكنك المساهمة في عدة مجالات:

1. **اختبار وتجربة العتاد**: 
   - التأكد من توصيل المستشعرات بشكل صحيح على اللوحة
   - اختبار عمل المضخات والصمامات الكهربائية
   - قياس دقة قراءات المستشعرات

2. **تطوير وكتابة الأكواد البرمجية**:
   - المساعدة في حل مشاكل التجميع والبرمجة
   - كتابة اختبارات تلقائية للكود
   - إضافة ميزات جديدة للنظام
   - تحسين الأداء وتحسين الكود

3. **تصميم واجهة المستخدم**:
   - تحسين التصميم وتجربة المستخدم
   - إضافة رسوم بيانية تفاعلية للبيانات التاريخية
   - تحسين سهولة الاستخدام على الهاتف

4. **كتابة التوثيق**:
   - كتابة دليل شامل للمستخدمين
   - إنشاء فيديوهات توضيحية لطريقة الاستخدام
   - ترجمة الواجهة للغة العربية
   - كتابة أمثلة وحالات استخدام عملية

---

## الخلاصة 📝

**نظام مراقبة وأتمتة الزراعة المائية** هو مشروع طموح يهدف لجعل الزراعة المائية **أسهل وأكثر ذكاءً** من خلال:
- مراقبة تلقائية مستمرة لجميع المعايير المهمة
- تحكم آلي ذكي بالمحاليل الغذائية
- واجهة سهلة وجميلة على الهاتف المحمول

تم إنجاز **أكثر من 60%** من المشروع، والآن نحتاج للتركيز على **ربط الأجزاء الثلاثة** (البرمجية المدمجة، الخادم، واجهة المستخدم) واختبار النظام بشكل كامل.

---

> [!IMPORTANT]
> **للمزيد من التفاصيل التقنية:**
> - [خطة التنفيذ الكاملة](file:///d:/Github/HydroMonitor/docs/implementation_plan.md)
> - [مخطط المهام](file:///d:/Github/HydroMonitor/docs/task.md)
> - [توثيق التوصيلات](file:///d:/Github/HydroMonitor/docs/pinout.md)
> - [ملخص الإنجازات](file:///d:/Github/HydroMonitor/docs/walkthrough.md)

---

**نرحب بمساعدتك في إكمال هذا المشروع! 🌱💚**

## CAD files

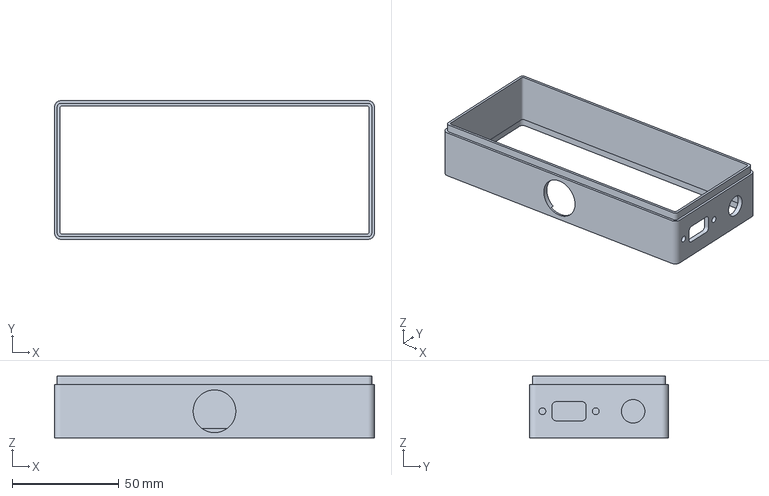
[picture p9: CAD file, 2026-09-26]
battery_riser.3mf
150.0 x 65.0 x 29.0 mm

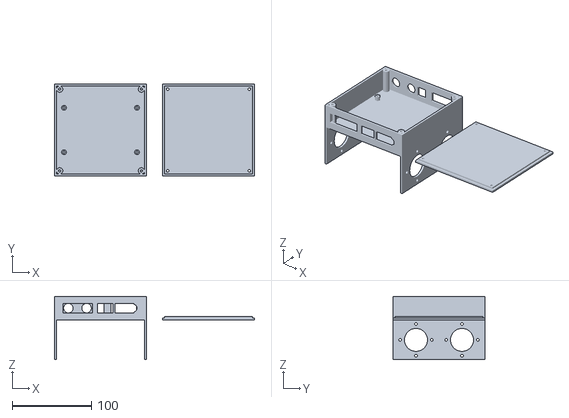
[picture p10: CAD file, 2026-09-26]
hardware/enclosure/integrated_enclosure.stl
252.0 x 116.0 x 80.0

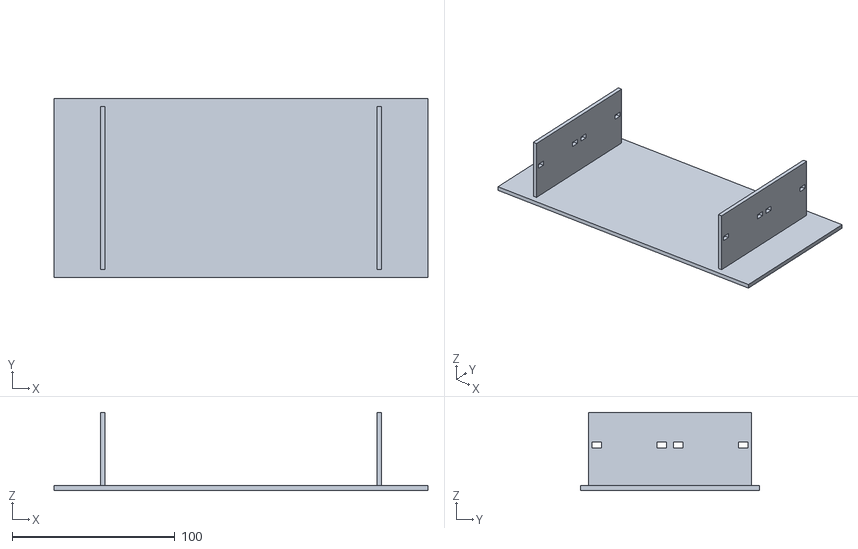
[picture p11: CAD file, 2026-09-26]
hardware/enclosure/extension_base.stl
230.0 x 110.0 x 48.0

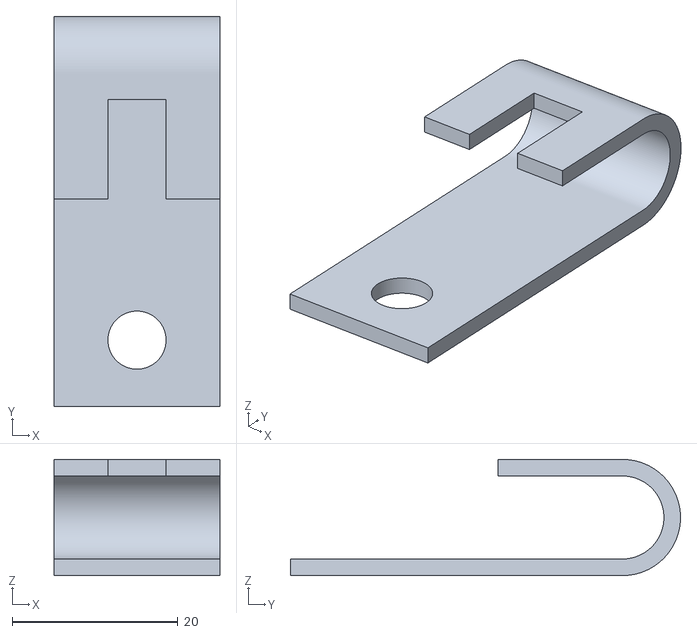
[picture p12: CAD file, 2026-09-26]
hook_clip.stl
20.0 x 47.0 x 14.0

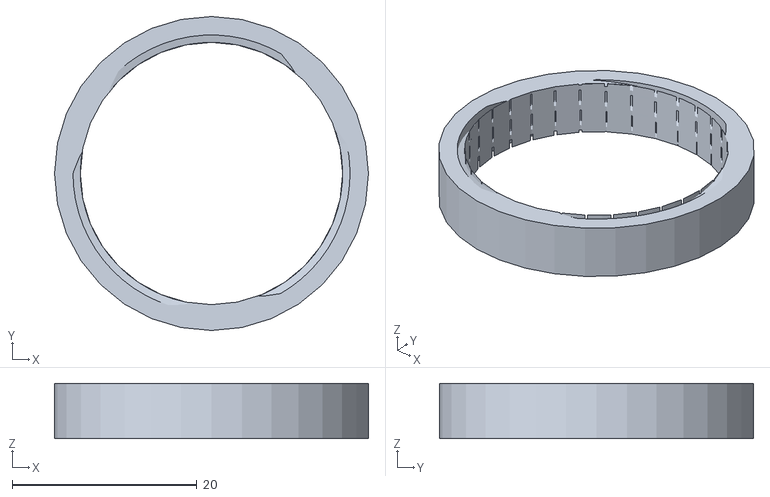
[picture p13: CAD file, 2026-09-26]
hardware/enclosure/thread_test.stl
34.0 x 34.0 x 6.00

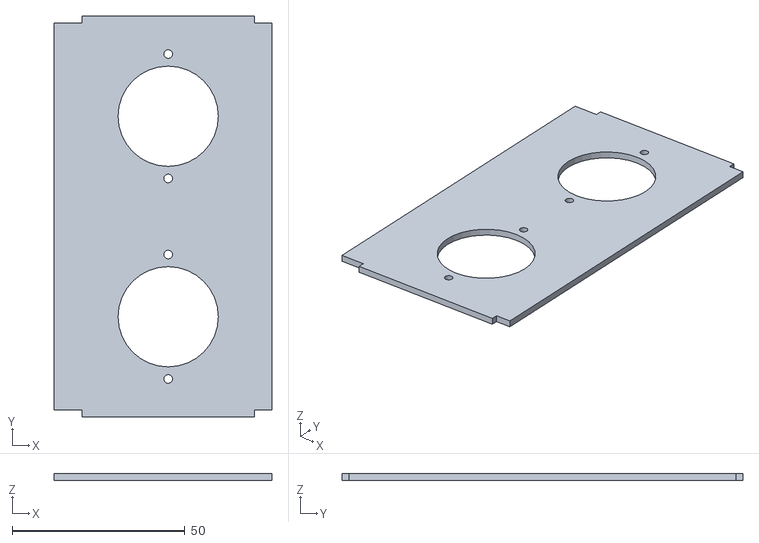
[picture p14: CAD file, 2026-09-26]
hardware/enclosure/right_pump_leg.stl
63.0 x 116.0 x 2.00

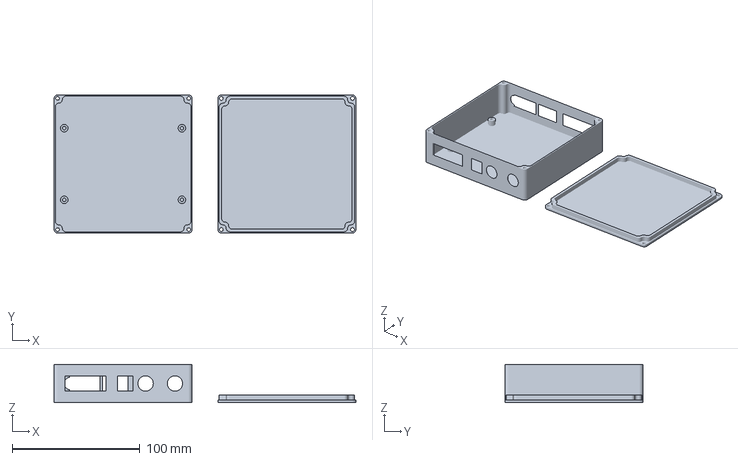
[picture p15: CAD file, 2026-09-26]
hardware/enclosure/enclosure.3mf
236.0 x 108.0 x 30.0 mm

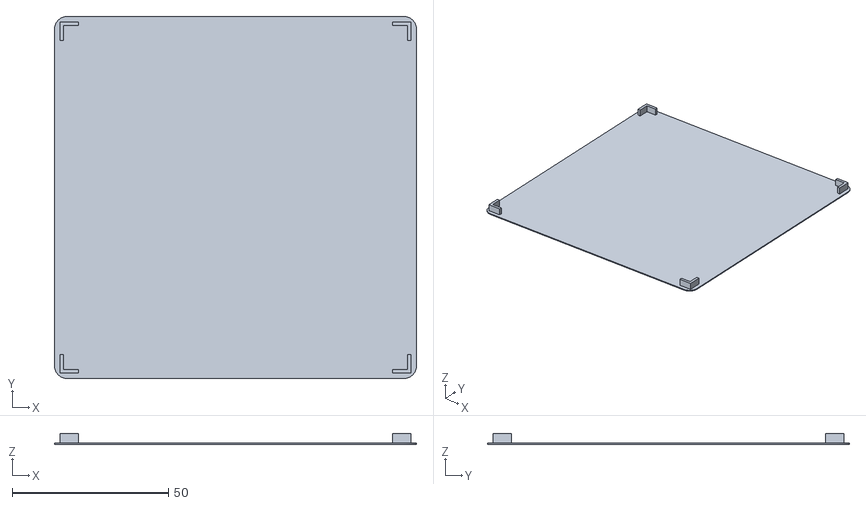
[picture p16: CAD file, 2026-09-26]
hardware/enclosure/enclosure_lid.stl
116.0 x 116.0 x 3.40

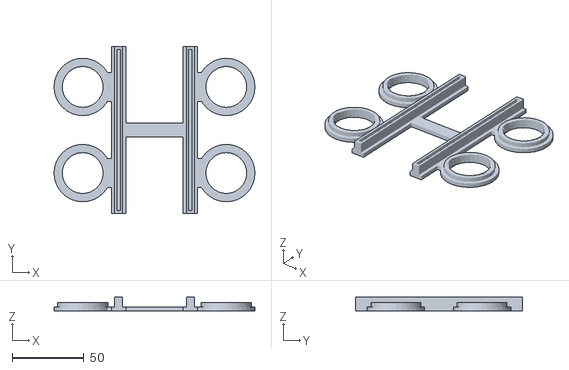
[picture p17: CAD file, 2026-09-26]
hardware/enclosure/bottle_holder.stl
140.0 x 116.0 x 10.00

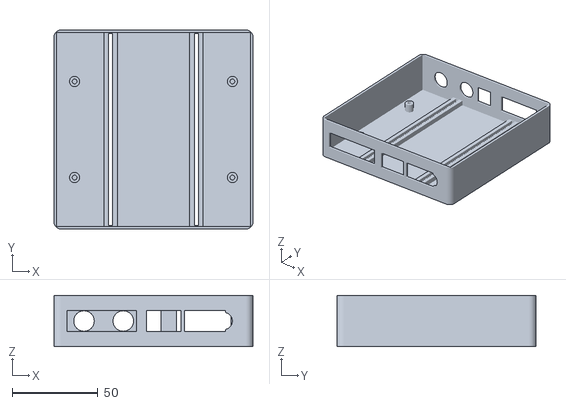
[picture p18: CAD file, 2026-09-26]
hardware/enclosure/enclosure_base.stl
116.0 x 116.0 x 30.0

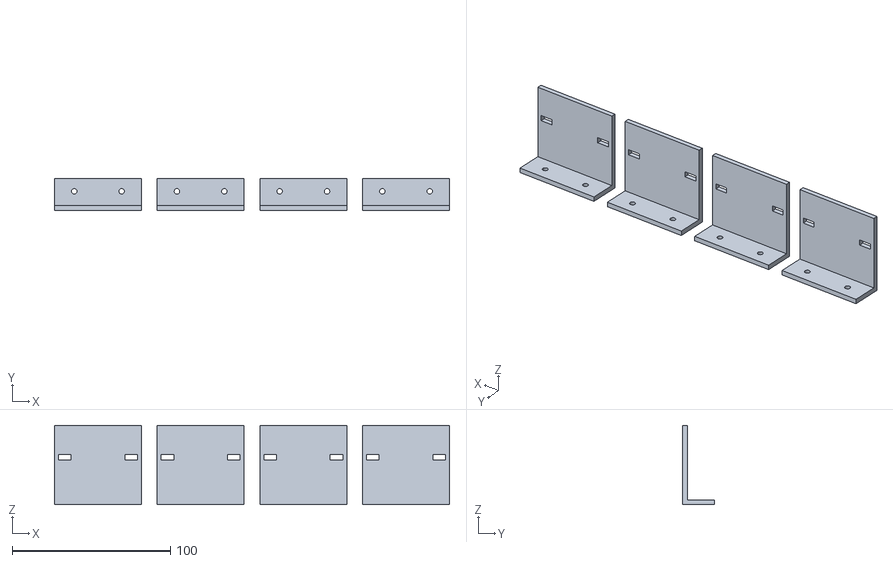
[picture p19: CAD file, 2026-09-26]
hardware/enclosure/pump_brackets.stl
250.0 x 20.0 x 50.0

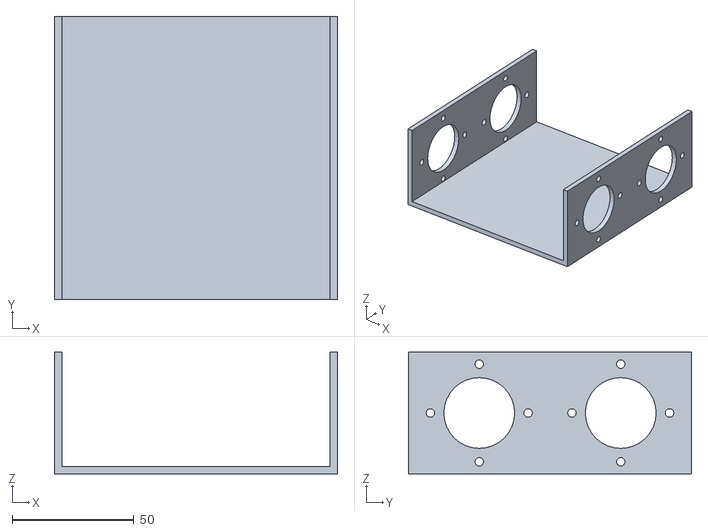
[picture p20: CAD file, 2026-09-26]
hardware/enclosure/undercarriage.stl
116.0 x 116.0 x 50.0

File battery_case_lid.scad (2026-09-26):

/* 
 * 7x3 18650 Battery Case Top Closure
 * Features: Screen cutout, Type-C hole, XT60E-F hole, 12V DC hole
 */

// --- MAIN DIMENSIONS ---
// The outer dimensions of your existing bottom case (the lid will slip over this)
case_length = 151.0; 
case_width = 65.0;   
lid_height = 30.0;     // Total height of this lid
wall_thickness = 2.0;
clearance = 0.4;       // Clearance for a snug slip fit

// --- TOP CUTOUTS (Z-Axis) ---
// Voltage / Battery Percentage Screen
screen_width = 43.0;
screen_height = 11.0;
screen_offset_x = 0;   // Distance from center along length
screen_offset_y = 15;  // Distance from center along width

// Type-C Hole
typec_width = 9.0;
typec_height = 3.5;
typec_offset_x = 0;
typec_offset_y = -10;

// --- FRONT CUTOUTS (Y-Axis, long side) ---
// XT60E-F Panel Mount
xt60_cutout_width = 19.0;
xt60_cutout_height = 12.0;
xt60_screw_spacing = 25.0;
xt60_screw_dia = 3.2; // M3 screws
xt60_offset_x = -30;  // Position along the front face
xt60_offset_z = 15;   // Height from the bottom edge

// 12V DC Barrel Jack Hole
dc_jack_dia = 8.0;    // Usually 8mm for 5.5x2.1mm jacks, or 11mm for larger ones
dc_offset_x = 30;
dc_offset_z = 15;


// --- RENDERING ---
$fn = 60; // Smoothness for cylinders/holes

difference() {
    // Main Body (Lid Outer)
    cube([case_length + (wall_thickness*2) + (clearance*2), 
          case_width + (wall_thickness*2) + (clearance*2), 
          lid_height], center=true);
    
    // Hollow out the inside (Lid Inner)
    translate([0, 0, -wall_thickness])
        cube([case_length + (clearance*2), 
              case_width + (clearance*2), 
              lid_height], center=true);
              
    // --- TOP CUTOUTS ---
    // Screen Cutout
    translate([screen_offset_x, screen_offset_y, lid_height/2 - wall_thickness/2])
        cube([screen_width, screen_height, wall_thickness * 4], center=true);
        
    // Type-C Cutout (Rounded rectangle)
    translate([typec_offset_x, typec_offset_y, lid_height/2 - wall_thickness/2])
        hull() {
            translate([typec_width/2 - typec_height/2, 0, 0])
                cylinder(h=wall_thickness * 4, d=typec_height, center=true);
            translate([-typec_width/2 + typec_height/2, 0, 0])
                cylinder(h=wall_thickness * 4, d=typec_height, center=true);
        }
        
    // --- FRONT CUTOUTS ---
    // Front face is at y = -(case_width/2 + wall_thickness/2 + clearance)
    // XT60E-F
    translate([xt60_offset_x, -(case_width/2 + wall_thickness + clearance), xt60_offset_z - lid_height/2]) {
        // Main connector cutout
        cube([xt60_cutout_width, wall_thickness * 4, xt60_cutout_height], center=true);
        // Screw holes
        translate([xt60_screw_spacing/2, 0, 0])
            rotate([90, 0, 0]) cylinder(h=wall_thickness * 4, d=xt60_screw_dia, center=true);
        translate([-xt60_screw_spacing/2, 0, 0])
            rotate([90, 0, 0]) cylinder(h=wall_thickness * 4, d=xt60_screw_dia, center=true);
    }
    
    // 12V DC Jack
    translate([dc_offset_x, -(case_width/2 + wall_thickness + clearance), dc_offset_z - lid_height/2])
        rotate([90, 0, 0]) cylinder(h=wall_thickness * 4, d=dc_jack_dia, center=true);
}

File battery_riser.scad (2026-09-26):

// Battery Box Riser
// ---------------------------------------------------------
// This part is designed to sit between the main bottom box
// and the lid, giving you extra vertical space.
// 
// You MUST measure your exact battery box and adjust 
// the dimensions below before printing!
// ---------------------------------------------------------

// --- Main Dimensions ---
// Measure the OUTSIDE of the green battery box.
outer_length = 151.0;   
outer_width = 65.0;     

// Measure the thickness of the green wall.
wall_thickness = 2.0;   

// Estimate how round the corners are.
corner_radius = 3.0;    

// --- Riser Dimensions ---
// How much extra vertical space you want (in mm).
riser_height = 30.0;    

// How deep the alignment lip should go into the bottom box.
insert_depth = 4.0;     

// Thickness of the alignment lip (usually thinner than the wall).
lip_thickness = 1.5;    

// Clearance (gap) so the lip easily slides into the box without jamming.
clearance = 0.4;        

// --- Render Settings ---
$fn = 64;

module rounded_rect(l, w, r) {
    if (r > 0) {
        hull() {
            translate([r, r]) circle(r=r);
            translate([l-r, r]) circle(r=r);
            translate([l-r, w-r]) circle(r=r);
            translate([r, w-r]) circle(r=r);
        }
    } else {
        square([l, w]);
    }
}

module riser() {
    // 1. Main Body (The new wall)
    // From Z = 0 upwards to riser_height
    translate([0, 0, 0])
    linear_extrude(height = riser_height) {
        difference() {
            // Outer profile
            rounded_rect(outer_length, outer_width, corner_radius);
            // Inner profile
            translate([wall_thickness, wall_thickness])
                rounded_rect(outer_length - 2*wall_thickness, outer_width - 2*wall_thickness, max(0.1, corner_radius - wall_thickness));
        }
    }
    
    // 2. Alignment Lip (Drops down into the original box)
    // From Z = 0 downwards to -insert_depth
    lip_outer_l = outer_length - 2*wall_thickness - clearance;
    lip_outer_w = outer_width - 2*wall_thickness - clearance;
    lip_offset_x = wall_thickness + clearance/2;
    lip_offset_y = wall_thickness + clearance/2;
    lip_corner_r = max(0.1, corner_radius - wall_thickness - clearance/2);
    
    translate([lip_offset_x, lip_offset_y, -insert_depth])
    linear_extrude(height = insert_depth + 0.1) { // +0.1 to perfectly fuse with main body
        difference() {
            // Lip outer profile
            rounded_rect(lip_outer_l, lip_outer_w, lip_corner_r);
            // Lip inner profile
            translate([lip_thickness, lip_thickness])
                rounded_rect(lip_outer_l - 2*lip_thickness, lip_outer_w - 2*lip_thickness, max(0.1, lip_corner_r - lip_thickness));
        }
    }
}

// Center the part for printing
translate([-outer_length/2, -outer_width/2, insert_depth])
    riser();

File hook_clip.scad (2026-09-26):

// Parametric Hanging Clip
// ---------------------------------------------------------
// Dimensions are in millimeters. Adjust these variables 
// to change the shape and size of the clip.
// ---------------------------------------------------------

// Main body dimensions
width = 20;           // Width of the flat bar
length = 40;          // Length of the main straight base part
thickness = 2;        // Thickness of the material

// Hole dimensions
hole_diameter = 7;
hole_offset = 8;      // Distance from the bottom edge to the center of the hole

// Hook (180 degree bend) dimensions
hook_inner_radius = 5;
hook_return_length = 15; // Length of the straight part that bends back

// Slot dimensions (the cutout in the hook part)
slot_width = 7;
slot_length = 12;

// ---------------------------------------------------------
// Rendering variables
$fn = 64;             // Curve resolution
hook_outer_radius = hook_inner_radius + thickness;

module part() {
    difference() {
        union() {
            // 1. Main Base Body
            // Centered on X, starting at Y=0, Z goes from 0 to thickness
            translate([-width/2, 0, 0])
                cube([width, length, thickness]);
            
            // 2. 180 Degree Bend
            // Center is at the end of the base: Y = length, Z = hook_outer_radius
            translate([0, length, hook_outer_radius])
                rotate([0, 90, 0])
                rotate_extrude(angle=180)
                    translate([hook_inner_radius, -width/2])
                        square([thickness, width]);
                        
            // 3. Return Hook Part (the straight section bending back)
            // Starts at Y = length, extends backwards to length - hook_return_length
            translate([-width/2, length - hook_return_length, hook_inner_radius*2 + thickness])
                cube([width, hook_return_length, thickness]);
        }
        
        // Subtract Base Hole
        translate([0, hole_offset, -1])
            cylinder(d=hole_diameter, h=thickness + 2);
            
        // Subtract Hook Slot
        // Cut into the return part of the hook
        translate([-slot_width/2, length - hook_return_length - 1, hook_inner_radius*2 + thickness - 1])
            cube([slot_width, slot_length + 1, thickness + 2]);
    }
}

// Render the part
part();

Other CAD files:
battery_riser.stl
hardware/enclosure/enclosure.stl

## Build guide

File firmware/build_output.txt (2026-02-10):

Processing esp32dev (platform: espressif32; board: esp32dev; framework: arduino)
--------------------------------------------------------------------------------
Verbose mode can be enabled via `-v, --verbose` option
CONFIGURATION: https://docs.platformio.org/page/boards/espressif32/esp32dev.html
PLATFORM: Espressif 32 (6.12.0) > Espressif ESP32 Dev Module
HARDWARE: ESP32 240MHz, 320KB RAM, 4MB Flash
DEBUG: Current (cmsis-dap) External (cmsis-dap, esp-bridge, esp-prog, iot-bus-jtag, jlink, minimodule, olimex-arm-usb-ocd, olimex-arm-usb-ocd-h, olimex-arm-usb-tiny-h, olimex-jtag-tiny, tumpa)
PACKAGES: 
 - framework-arduinoespressif32 @ 3.20017.241212+sha.dcc1105b 
 - tool-esptoolpy @ 2.40900.250804 (4.9.0) 
 - toolchain-xtensa-esp32 @ 8.4.0+2021r2-patch5
LDF: Library Dependency Finder -> https://bit.ly/configure-pio-ldf
LDF Modes: Finder ~ chain, Compatibility ~ soft
Found 41 compatible libraries
Scanning dependencies...
Dependency Graph
|-- WiFiManager @ 2.0.17
|-- PubSubClient @ 2.8.0
|-- ArduinoJson @ 6.21.5
|-- OneWire @ 2.3.8
|-- DallasTemperature @ 3.11.0
|-- HydroActuators
|-- HydroDosingPumps
|-- HydroMQTT
Building in release mode
Compiling .pio\build\esp32dev\src\main.cpp.o
Building .pio\build\esp32dev\bootloader.bin
Generating partitions .pio\build\esp32dev\partitions.bin
esptool.py v4.9.0
Creating esp32 image...
Merged 1 ELF section
Successfully created esp32 image.
Compiling .pio\build\esp32dev\lib9f5\WiFi\WiFi.cpp.o
Compiling .pio\build\esp32dev\lib9f5\WiFi\WiFiAP.cpp.o
Compiling .pio\build\esp32dev\lib9f5\WiFi\WiFiClient.cpp.o
Compiling .pio\build\esp32dev\lib9f5\WiFi\WiFiGeneric.cpp.o
Compiling .pio\build\esp32dev\lib9f5\WiFi\WiFiMulti.cpp.o
Compiling .pio\build\esp32dev\lib9f5\WiFi\WiFiSTA.cpp.o
Compiling .pio\build\esp32dev\lib9f5\WiFi\WiFiScan.cpp.o
Compiling .pio\build\esp32dev\lib9f5\WiFi\WiFiServer.cpp.o
Compiling .pio\build\esp32dev\lib9f5\WiFi\WiFiUdp.cpp.o
Compiling .pio\build\esp32dev\lib8e2\DNSServer\DNSServer.cpp.o
Compiling .pio\build\esp32dev\libe9e\ESPmDNS\ESPmDNS.cpp.o
Archiving .pio\build\esp32dev\lib8e2\libDNSServer.a
Indexing .pio\build\esp32dev\lib8e2\libDNSServer.a
pio : src/main.cpp: In 
function 'void loop()':
At line:1 char:51
+ ... ut-File -FilePath 
build_output.txt 
-InputObject (pio run 
2>&1 | Out-S ...
+                        
                         
     ~~~~~~~~~~~~
    + CategoryInfo       
       : NotSpecified:   
  (src/main.cpp: In fu   
 nction 'void loop()'    
::String) [], Remote    
Exception
    + FullyQualifiedErro 
   rId : NativeCommandE  
  rror
 
src/main.cpp:158:67: 
error: no matching 
function for call to 'Hyd
roMQTT::publishSensor(Str
ing&, uint8_t)'
               mqtt.publi
shSensor(pumpName, 
dosingPumps.getSpeed(i));

                 ^
In file included from 
src/main.cpp:4:
lib/HydroMQTT/HydroMQTT.h
:17:10: note: candidate: 
'void HydroMQTT::publishS
ensor(const char*, 
float)'
     void 
publishSensor(const 
char* sensorName, float 
value);
          ^~~~~~~~~~~~~
lib/HydroMQTT/HydroMQTT.h
:17:10: note:   no known 
conversion for argument 
1 from 'String' to 
'const char*'
Compiling .pio\build\esp32dev\libdc4\Update\HttpsOTAUpdate.cpp.o
*** [.pio\build\esp32dev\
src\main.cpp.o] Error 1
=========================
 [FAILED] Took 14.70 
seconds 
=========================

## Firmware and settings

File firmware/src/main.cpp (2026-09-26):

#include <Arduino.h>
#include <WiFi.h>
#include <HTTPClient.h>
#include <SPIFFS.h>
#include <WiFiManager.h>
#include <WebServer.h>
#include <LittleFS.h>
#include <ArduinoJson.h>
#include <ESPmDNS.h>
#include <ArduinoOTA.h>
#include <ElegantOTA.h>
#include <WiFiClientSecure.h>
#include <ArduinoWebsockets.h>
#include <HTTPUpdate.h>
#include <uri/UriBraces.h>

#define CLOUD_HUB_URL "http://192.168.1.100:8000"
#include <HydroActuators.h>
#include <HydroSensors.h>
#include <HydroDosingPumps.h>
#include <HydroControl.h>

// Shift Register Pins
#define PIN_SR_DATA 26
#define PIN_SR_CLOCK 27
#define PIN_SR_LATCH 14
#define PIN_SR_CLEAR 12

// Dosing Pump Pins
#define PIN_DOSING_A 18
#define PIN_DOSING_B 19
#define PIN_DOSING_PH 21
#define PIN_DOSING_AUX 22

// Digital Expansion Port 0: DS18B20 water temp (OneWire needs bidirectional - use Out pin)
#define PIN_SENSOR_DS18B20 4
// Digital Expansion Port 1: DHT21/AM2301 air temp+humidity (data pin)
#define PIN_SENSOR_DHT 17
// DC Resistance / Water Level
#define PIN_SENSOR_LEVEL 32
// Current Sense (built into pump headers)
#define PIN_SENSOR_CURRENT 35
// pH Probe on pH BNC #0
#define PIN_SENSOR_PH 36
#define PIN_SENSOR_EC 34 // EC_0 is on pin 34
#define PIN_EC_M_GATE 25
#define PIN_EC_P_GATE 15

HydroActuators actuators(PIN_SR_DATA, PIN_SR_CLOCK, PIN_SR_LATCH, PIN_SR_CLEAR);
HydroDosingPumps dosingPumps(PIN_DOSING_A, PIN_DOSING_B, PIN_DOSING_PH, PIN_DOSING_AUX);
HydroSensors sensors(PIN_SENSOR_DS18B20, PIN_SENSOR_DHT, PIN_SENSOR_LEVEL, PIN_SENSOR_CURRENT, PIN_SENSOR_PH, PIN_SENSOR_EC, PIN_EC_M_GATE, PIN_EC_P_GATE);

HydroControl hydroControl(sensors, dosingPumps);
WebServer server(80);


using namespace websockets;
WebsocketsServer webSocket;
std::vector<WebsocketsClient> wsClients;

String getApiStateJson() {
    StaticJsonDocument<1024> doc;
    doc["firmware_version"] = "2.0.2";
    doc["ph"] = sensors.getPH();
    doc["ec"] = sensors.getEC();
    doc["waterTemp"] = sensors.getWaterTemp();
    doc["airTemp"] = sensors.getAirTemp();
    doc["humidity"] = sensors.getHumidity();
    doc["waterLevel"] = sensors.isWaterLevelOk() ? 100 : 0;
    doc["pumpState"] = 0;
    
    // Debug variables
    doc["ec_R"] = sensors.getLastEcR();
    doc["ec_V"] = sensors.getLastEcV();
    doc["ec_sum"] = sensors.getLastEcSum();
    
    // Pump statuses
    JsonArray pumps = doc.createNestedArray("pumps");
    for (int i=0; i<4; i++) {
        JsonObject pump = pumps.createNestedObject();
        pump["id"] = i;
        pump["speed"] = dosingPumps.getSpeed(i);
        pump["is_dosing"] = dosingPumps.isDosing(i);
    }

    // Automation Config
    JsonObject auto_config = doc.createNestedObject("automation_config");
    JsonObject targets = auto_config.createNestedObject("targets");
    targets["ph"] = hydroControl.getPhTarget();
    targets["ec"] = hydroControl.getEcTarget();
    
    JsonObject tolerances = auto_config.createNestedObject("tolerances");
    tolerances["ph"] = hydroControl.getPhTolerance();
    tolerances["ec"] = hydroControl.getEcTolerance();
    
    JsonObject enabled = auto_config.createNestedObject("enabled");
    enabled["ph"] = hydroControl.isPhEnabled();
    enabled["ec"] = hydroControl.isEcEnabled();
    
    auto_config["active_crop"] = "";

    String response;
    serializeJson(doc, response);
    return response;
}

void handleApiState() {
    String response = getApiStateJson();
    server.sendHeader("Access-Control-Allow-Origin", "*");
    server.send(200, "application/json", response);
}

void handleApiConfig() {
    StaticJsonDocument<512> doc;
    JsonObject targets = doc.createNestedObject("targets");
    targets["ph"] = hydroControl.getPhTarget();
    targets["ec"] = hydroControl.getEcTarget();
    
    JsonObject tolerances = doc.createNestedObject("tolerances");
    tolerances["ph"] = hydroControl.getPhTolerance();
    tolerances["ec"] = hydroControl.getEcTolerance();
    
    JsonObject enabled = doc.createNestedObject("enabled");
    enabled["ph"] = hydroControl.isPhEnabled();
    enabled["ec"] = hydroControl.isEcEnabled();

    String response;
    serializeJson(doc, response);
    server.sendHeader("Access-Control-Allow-Origin", "*");
    server.send(200, "application/json", response);
}

void handleApiConfigParameter() {
    if (server.method() == HTTP_OPTIONS) {
        server.sendHeader("Access-Control-Allow-Origin", "*");
        server.sendHeader("Access-Control-Allow-Methods", "POST, OPTIONS");
        server.sendHeader("Access-Control-Allow-Headers", "Content-Type");
        server.send(204);
        return;
    }
    
    if (server.hasArg("plain") == false) {
        server.sendHeader("Access-Control-Allow-Origin", "*");
        server.send(400, "text/plain", "Body not received");
        return;
    }
    
    String body = server.arg("plain");
    StaticJsonDocument<256> doc;
    DeserializationError error = deserializeJson(doc, body);
    
    if (error) {
        server.sendHeader("Access-Control-Allow-Origin", "*");
        server.send(400, "text/plain", "Invalid JSON");
        return;
    }
    
    const char* parameter = doc["parameter"];
    if (!parameter) {
        server.sendHeader("Access-Control-Allow-Origin", "*");
        server.send(400, "text/plain", "Missing parameter");
        return;
    }
    
    if (strcmp(parameter, "ph") == 0) {
        float target = doc.containsKey("target") ? doc["target"].as<float>() : hydroControl.getPhTarget();
        float tol = doc.containsKey("tolerance") ? doc["tolerance"].as<float>() : hydroControl.getPhTolerance();
        bool en = doc.containsKey("enabled") ? doc["enabled"].as<bool>() : hydroControl.isPhEnabled();
        
        hydroControl.setPhTarget(target, tol);
        hydroControl.enableAutomation(en, hydroControl.isEcEnabled());
        hydroControl.saveConfig();
    } 
    else if (strcmp(parameter, "ec") == 0) {
        float target = doc.containsKey("target") ? doc["target"].as<float>() : hydroControl.getEcTarget();
        float tol = doc.containsKey("tolerance") ? doc["tolerance"].as<float>() : hydroControl.getEcTolerance();
        bool en = doc.containsKey("enabled") ? doc["enabled"].as<bool>() : hydroControl.isEcEnabled();
        
        hydroControl.setEcTarget(target, tol);
        hydroControl.enableAutomation(hydroControl.isPhEnabled(), en);
        hydroControl.saveConfig();
    }
    
    server.sendHeader("Access-Control-Allow-Origin", "*");
    server.send(200, "application/json", "{\"status\":\"ok\"}");
}

void postTelemetryToCloud() {
    if (WiFi.status() == WL_CONNECTED) {
        WiFiClient client;
        HTTPClient http;
        http.begin(client, CLOUD_HUB_URL "/api/telemetry/report");
        http.addHeader("Content-Type", "application/json");
        
        String payload = getApiStateJson();
        int httpResponseCode = http.POST(payload);
        
        if (httpResponseCode > 0) {
            Serial.printf("Telemetry POST success: %d\n", httpResponseCode);
        } else {
            Serial.printf("Telemetry POST failed: %s\n", http.errorToString(httpResponseCode).c_str());
        }
        http.end();
    }
}

void checkForFirmwareUpdates() {
    if (WiFi.status() == WL_CONNECTED) {
        WiFiClient client;
        HTTPClient http;
        http.begin(client, CLOUD_HUB_URL "/api/firmware/check");
        int httpResponseCode = http.GET();
        
        if (httpResponseCode == 200) {
            String payload = http.getString();
            StaticJsonDocument<512> doc;
            DeserializationError error = deserializeJson(doc, payload);
            
            if (!error && doc.containsKey("url")) {
                String updateUrl = doc["url"].as<String>();
                Serial.println("New firmware found! Updating from: " + updateUrl);
                
                t_httpUpdate_return ret = httpUpdate.update(client, updateUrl);
                switch (ret) {
                    case HTTP_UPDATE_FAILED:
                        Serial.printf("HTTP_UPDATE_FAILED Error (%d): %s\n", httpUpdate.getLastError(), httpUpdate.getLastErrorString().c_str());
                        break;
                    case HTTP_UPDATE_NO_UPDATES:
                        Serial.println("HTTP_UPDATE_NO_UPDATES");
                        break;
                    case HTTP_UPDATE_OK:
                        Serial.println("HTTP_UPDATE_OK");
                        break;
                }
            } else {
                Serial.println("No update url found or JSON invalid");
            }
        } else {
            Serial.printf("Firmware check GET failed: %s\n", http.errorToString(httpResponseCode).c_str());
        }
        http.end();
    }
}

void setup() {
    Serial.begin(115200);
    Serial.println("\n\nHydroponic Standalone System - Booting...");

    // Initialize Hardware
    actuators.begin();
    dosingPumps.begin();
    sensors.begin();
    hydroControl.begin();

    // Mount LittleFS for the Web Dashboard
    if (!LittleFS.begin(true)) {
        Serial.println("An Error has occurred while mounting LittleFS");
    } else {
        Serial.println("LittleFS Mounted Successfully");
    }

    WiFiManager wm;
    bool res = wm.autoConnect("HydroMisc-Setup", "password");
    if(!res) {
        Serial.println("Failed to connect to WiFi");
    } else {
        Serial.print("Connected! IP Address: ");
        Serial.println(WiFi.localIP());
    }

    if (MDNS.begin("hydromonitor")) {
        Serial.println("MDNS responder started at http://hydromonitor.local");
        MDNS.addService("http", "tcp", 80);
    } else {
        Serial.println("Error setting up MDNS responder!");
    }

    // Configure ArduinoOTA
    ArduinoOTA.setHostname("hydromonitor");
    ArduinoOTA.onStart([]() {
        String type;
        if (ArduinoOTA.getCommand() == U_FLASH) {
            type = "sketch";
        } else { // U_SPIFFS / U_LITTLEFS
            type = "filesystem";
            Serial.println("Start updating filesystem");
            server.stop();
            // NOTE: if updating SPIFFS this would be the place to unmount SPIFFS using SPIFFS.end()
            LittleFS.end();
        }
        Serial.println("Start updating " + type);
    });
    ArduinoOTA.onEnd([]() {
        Serial.println("\nEnd");
    });
    ArduinoOTA.onProgress([](unsigned int progress, unsigned int total) {
        Serial.printf("Progress: %u%%\r", (progress / (total / 100)));
    });
    ArduinoOTA.onError([](ota_error_t error) {
        Serial.printf("Error[%u]: ", error);
        if (error == OTA_AUTH_ERROR) Serial.println("Auth Failed");
        else if (error == OTA_BEGIN_ERROR) Serial.println("Begin Failed");
        else if (error == OTA_CONNECT_ERROR) Serial.println("Connect Failed");
        else if (error == OTA_RECEIVE_ERROR) Serial.println("Receive Failed");
        else if (error == OTA_END_ERROR) Serial.println("End Failed");
    });
    ArduinoOTA.begin();

    ElegantOTA.begin(&server);    // Start ElegantOTA

    // --- WebSockets ---
    webSocket.listen(81);

    // --- Global CORS handler for OPTIONS requests ---
    server.onNotFound([]() {
        if (server.method() == HTTP_OPTIONS) {
            server.sendHeader("Access-Control-Allow-Origin", "*");
            server.sendHeader("Access-Control-Allow-Methods", "GET, POST, OPTIONS");
            server.sendHeader("Access-Control-Allow-Headers", "Content-Type");
            server.send(204);
        } else {
            server.send(404, "text/plain", "Not found");
        }
    });


    // --- API Endpoints ---
    server.on("/api/state", HTTP_GET, handleApiState);
    server.on("/api/config", HTTP_GET, handleApiConfig);
    server.on("/api/config/parameter", HTTP_POST, handleApiConfigParameter);
    
    // Actuators
    server.on(UriBraces("/api/actuators/solenoid/{}/{}"), HTTP_POST, []() {
        int index = server.pathArg(0).toInt();
        String stateStr = server.pathArg(1);
        actuators.setSolenoid(index, (stateStr == "1" || stateStr == "true"));
        actuators.commit();
        server.sendHeader("Access-Control-Allow-Origin", "*");
        server.send(200, "application/json", "{\"status\":\"ok\"}");
    });

    server.on(UriBraces("/api/actuators/pump/{}/{}"), HTTP_POST, []() {
        int index = server.pathArg(0).toInt();
        String stateStr = server.pathArg(1);
        actuators.setPump(index, (stateStr == "1" || stateStr == "true"));
        actuators.commit();
        server.sendHeader("Access-Control-Allow-Origin", "*");
        server.send(200, "application/json", "{\"status\":\"ok\"}");
    });

    server.on(UriBraces("/api/actuators/main_pump/{}"), HTTP_POST, []() {
        String stateStr = server.pathArg(0);
        actuators.setBigPump(stateStr == "1" || stateStr == "true");
        actuators.commit();
        server.sendHeader("Access-Control-Allow-Origin", "*");
        server.send(200, "application/json", "{\"status\":\"ok\"}");
    });

    // Dosing & Calibration
    server.on("/api/dosing/manual", HTTP_POST, []() {
        if (!server.hasArg("plain")) {
            server.sendHeader("Access-Control-Allow-Origin", "*");
            server.send(400, "text/plain", "Missing body");
            return;
        }
        StaticJsonDocument<256> doc;
        deserializeJson(doc, server.arg("plain"));
        int pump_index = doc["pump_index"];
        int duration_ms = doc["duration_ms"];
        int speed = doc.containsKey("speed") ? doc["speed"].as<int>() : 100;
        dosingPumps.dose(pump_index, duration_ms, speed);
        server.sendHeader("Access-Control-Allow-Origin", "*");
        server.send(200, "application/json", "{\"status\":\"ok\"}");
    });
    
    server.on("/api/dosing/reset", HTTP_POST, []() {
        hydroControl.resetControllers();
        server.sendHeader("Access-Control-Allow-Origin", "*");
        server.send(200, "application/json", "{\"status\":\"ok\"}");
    });

    server.on("/api/calibrate", HTTP_POST, []() {
        if (!server.hasArg("plain")) {
            server.sendHeader("Access-Control-Allow-Origin", "*");
            server.send(400, "text/plain", "Missing body");
            return;
        }
        StaticJsonDocument<256> doc;
        deserializeJson(doc, server.arg("plain"));
        sensors.processCalibration(doc["sensor"].as<String>(), doc["command"].as<String>());
        server.sendHeader("Access-Control-Allow-Origin", "*");
        server.send(200, "application/json", "{\"status\":\"ok\"}");
    });

    // Fake Endpoints for Frontend Compatibility
    server.on(UriBraces("/api/config/crop/{}"), HTTP_POST, []() {
        server.sendHeader("Access-Control-Allow-Origin", "*");
        server.send(200, "application/json", "{\"status\":\"ok\"}");
    });

    server.on("/api/dosing/history", HTTP_GET, []() {
        server.sendHeader("Access-Control-Allow-Origin", "*");
        server.send(200, "application/json", "{\"history\":[]}");
    });

    server.on("/api/history", HTTP_GET, []() {
        server.sendHeader("Access-Control-Allow-Origin", "*");
        server.send(200, "application/json", "[]");
    });

    // Serve the frontend explicitly because serveStatic has a bug with index.html
    server.on("/", HTTP_GET, []() {
        File file = LittleFS.open("/index.html", "r");
        if (!file) {
            server.send(500, "text/plain", "Failed to open index.html");
            return;
        }
        server.streamFile(file, "text/html");
        file.close();
    });

    server.serveStatic("/", LittleFS, "/");

    server.begin();
    Serial.println("HTTP server started");
}

void loop() {
    server.handleClient();
    ArduinoOTA.handle();

    // Accept new websocket connections
    if (webSocket.poll()) {
        WebsocketsClient client = webSocket.accept();
        if (client.available()) {
            Serial.println("WS Client Connected!");
            wsClients.push_back(client);
        }
    }

    // Cleanup disconnected clients and poll active ones
    for (size_t i = 0; i < wsClients.size(); i++) {
        if (!wsClients[i].available()) {
            wsClients.erase(wsClients.begin() + i);
            i--;
        } else {
            wsClients[i].poll();
        }
    }
    
    if (!sensors.isWaterLevelOk()) {
        actuators.setPump(0, false);
        actuators.commit();
        dosingPumps.stopAll(); // EMERGENCY STOP
    }
    
    // Always update dosing pumps so timers can run and stop pumps safely
    dosingPumps.update();

    sensors.update();
    hydroControl.update(); // Run autonomous PID loop

    // Status LED blink & WS Broadcast
    static unsigned long lastBlink = 0;
    static bool ledState = false;
    if (millis() - lastBlink > 1000) {
        lastBlink = millis();
        ledState = !ledState;
        actuators.setDebugLed(ledState);
        actuators.commit();
        
        String json = getApiStateJson();
        for (auto& client : wsClients) {
            client.send(json);
        }
    }

    static unsigned long lastTelemetryTime = 0;
    if (millis() - lastTelemetryTime > 60000) {
        lastTelemetryTime = millis();
        postTelemetryToCloud();
    }

    static unsigned long lastFirmwareCheck = 0;
    if (millis() - lastFirmwareCheck > 600000) {
        lastFirmwareCheck = millis();
        checkForFirmwareUpdates();
    }
}

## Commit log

2026-02-10 Fix HydroDosingPumps header include and type mismatch errors
    [main.cpp]
2026-02-22 fix: add .gitignore, README, migrate Pydantic v2, commit frontend source files
    - Add .gitignore to exclude node_modules, dist, __pycache__, config.json, firmware build artifacts
    - Add README.md with project overview, setup instructions, config reference
    - Migrate config_manager.py to Pydantic v2: @field_validator, model_validate, model_dump
    - Remove deprecated @app.on_event('startup') - fold control_loop into lifespan context manager
    - Replace .dict() with .model_dump() in main.py config endpoint
    - Stage all frontend src/ components, hooks, services (Dashboard, ControlPanel, AutomationStatus, ParameterConfig, SensorCard, useWebSocket, api.js)
    - Remove dist/ from git tracking (now excluded by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
2026-02-22 feat: add GitHub Pages demo site with landing page and React app build
2026-03-12 style: simplify landing page text
2026-03-13 feat: complete calibration wizard and hardware math
2026-03-15 feat: complete premium 2d bento box redesign with framer motion
2026-05-24 feat: migrate active crop state to python backend to fix cross-device syncing
    [main.cpp]
2026-05-27 perf: lazy load components and switch to webp images to drastically improve initial page load time on ESP32
2026-06-09 docs: add comprehensive README with pinout, architecture, API reference, MQTT topics, network ports, and enclosure guide
2026-06-10 fix: auto-detect dev environment to resolve API routing and support legacy ESP32 payload keys
    [main.cpp]
2026-06-10 fix: parameter config crash and configure vite for ESP32 short filenames
    [main.cpp]
2026-06-10 fix: prevent ESP32 from resetting active crop to null
    [main.cpp]
2026-09-26 chore: Apply latest changes from local environment
    [battery_case_lid.scad, battery_riser.3mf, battery_riser.scad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]
2026-09-26 docs: Replace hardware mapping table with flowchart
2026-09-26 fix(firmware): Map Main Pump control to physical Pump Port 0 (Bit 8)

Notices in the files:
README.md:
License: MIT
